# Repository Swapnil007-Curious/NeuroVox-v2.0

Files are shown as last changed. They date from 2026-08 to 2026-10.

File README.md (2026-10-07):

# NeuroVox v2.0

A forearm band that reads tiny muscle signals and turns them into spoken sentences. It's for people who can't talk anymore (ALS, stroke, vocal cord damage, some spinal injuries) but can still twitch a muscle in their forearm, which turns out to be most of them for a long time.

device-on-hand

**Hardware:** ₹10,000
**Software (companion website + AI voice):** ₹20,000 per year

For comparison, commercial AAC devices (eye trackers, switch boards, dedicated speech generators) go for roughly ₹85,000 to well over ₹12 lakh, and most of them need a clinician to set up. That gap is basically the whole reason this project exists.

---

## Why

Stephen Hawking ran his whole speech system off one cheek muscle. The idea here is the same, just moved to the forearm and built out of parts you can actually order from LCSC.

The part I cared about most is the output. A lot of cheap assistive projects stop at "the device can say yes or no." That's not much better than a call bell. NeuroVox only classifies four gestures on the board, but the companion website hands that label to an LLM along with the time of day, who the person is talking to, and what was just said, and gets back a real sentence. Same YES gesture can come out as "Yes, the pain's still there" or "Yes, let's go outside" depending on what was asked a second ago.

---

## How it works

1. **Electrodes.** Four standard 2" x 2" TENS pads stick on the skin. Two go over the flexor digitorum superficialis (inner forearm) and two over the extensor digitorum (outer forearm). Leads plug into the board through JST-SH connectors. The pads are NOT built into the enclosure, I tried that early on and it doesn't work because the two muscle groups are on opposite sides of the arm.
2. **Analog front end.** Four AD8232s amplify and filter the microvolt signals. An INA333 does extra differential conditioning on two channels.
3. **ADC.** An ADS1299 (24 bit, biosignal grade) samples all four channels over SPI. Way better resolution than the ESP32's own ADC.
4. **Classification on the board.** The ESP32-S3 smooths each channel into an envelope, compares it to a threshold that adapts to the person over time, and counts pulses. 1 pulse = YES, 2 = NO, 3 = HELP, 4 or more = WAIT. A BNO055 IMU throws out samples when the arm moves suddenly so a wave of the hand doesn't get read as a gesture.
5. **Bluetooth.** The gesture label plus a confidence score goes out over BLE (something like `CH1:YES:91%`).
6. **Sentence + voice.** The companion website receives it, gets a sentence from Claude, shows it on screen and speaks it out loud in the chosen language (English, Hindi, Marathi, Tamil, Bengali and a few others).

Muscle twitch to spoken sentence is meant to land in under two seconds, most of that is network time not the board.

---

## The board



2 layer FR4, **220mm x 50mm**, designed in KiCad 8. It's long and skinny on purpose so it runs along the forearm instead of across it.

The board is split into three zones along its length:

| Zone | Position | What's in it |
|---|---|---|
| Power | 0 to 60mm | MCP73831 Li-Po charger, TPS61023 boost (5V), AMS1117 3.3V regulator, USB-C input |
| Analog | 60 to 150mm | 4x AD8232, ADS1299, INA333, electrode connectors J3 to J6 |
| Digital | 150 to 220mm | ESP32-S3-WROOM-1-N8, BNO055 IMU, DRV2605L haptic driver, MAX98357A audio amp, RGB LEDs, buzzer, programming header J7 |

Analog and digital grounds are separate pours that only meet at one point, a ferrite bead right where the analog zone ends. The ESP32's antenna sits at the right edge with no copper under it.

**Why 220mm and not 200mm:** the first version was 200mm and the analog section was too packed. There was one ground connection near the instrumentation amp that just could not be routed, I checked it with an exhaustive pathfinding run, not just the autorouter giving up. Stretching the board 20mm and giving the analog zone 90mm instead of 65mm fixed it. If you fork this and want it smaller, expect that fight again.

### Pin map (real hardware)

| Function | GPIO |
|---|---|
| ADS1299 SPI CLK / MOSI / MISO / CS / DRDY | 10, 11, 12, 13, 14 |
| I2C SDA / SCL (BNO055, DRV2605L) | 21, 18 |
| Haptic enable | 8 |
| I2S to MAX98357A | 15, 16, 17 |
| Status LEDs | 2, 4, 47 |
| Buzzer | 48 |

### Fab notes

- You need **Standard PCBA** at JLCPCB, not Economic. The ESP32-S3 module, the MAX98357A (WLCSP) and the DRV2605L (DSBGA) aren't hand solderable at any sane yield.
- Standard PCBA adds temporary 5mm rails on the long edges for the pick and place machine. Ask for V-scores so they snap off and you get the real 220 x 50mm board back.
- The DRV2605L's center ball needs via-in-pad to escape. Mention it in the order notes.
- Gerbers and the full `.kicad_pcb` are in `/PCB`. I didn't make a separate schematic file for this revision.

---

## Firmware

FreeRTOS on the ESP32-S3, four tasks so the Bluetooth stack can't mess up sample timing:

| Task | Core | Priority | Job |
|---|---|---|---|
| ADC sampling | 0 | 5 | reads all 4 channels into a ring buffer |
| Gesture classifier | 1 | 3 | envelope, adaptive threshold, pulse counting, confidence |
| BLE dispatcher | 1 | 1 | sends gesture strings to the website |
| IMU monitor | 1 | 1 | flags motion over 1.5G so those samples get dropped |

A few details that matter for accuracy:

- Envelope is an exponential moving average (alpha 0.05).
- Contractions shorter than 30ms are ignored, they're almost always noise.
- A gesture only gets confirmed after 400ms of quiet, so a slow double pulse doesn't get read as two singles.
- The threshold for each channel updates off a rolling average of recent peaks, because signal strength changes person to person and also drifts for the same person as muscles get tired. A threshold set on day one is wrong by day thirty, especially with something progressive like ALS.
- All four channels are treated the same. An older board revision had a ground problem on two channels and the firmware briefly weighted them differently, that got removed once the redesign fixed the actual problem.

BLE service UUID: `180d1000-1234-1000-8000-00805f9b34fb`
Characteristic: `2a371000-1234-1000-8000-00805f9b34fb`
Device name: `NeuroVox-v2`

**Current state, honestly:** the firmware in `/FIRMWARE` is a validation build. It runs the full classification pipeline against potentiometers standing in for the EMG front end and an MPU6050 standing in for the BNO055, which let me test the logic without waiting on boards. Flip `SIM_BUILD` to false for hardware. The piece still left is swapping the analog reads for a proper SPI driver talking to the ADS1299 and moving I2C to GPIO21/18. That happens when the assembled boards are back.

**On accuracy:** my target is around 88 to 90% gesture accuracy after a short per person calibration (about 10 contractions per gesture), tested seated with the arm resting. I haven't measured that on real muscle yet because the boards aren't made yet, so please don't quote it as a result. When I test I'll report each channel separately and then combined.

---

## Enclosure

ezgif-frame-200

Two part snap fit, no screws holding the halves together (four M2 screws just hold the PCB to standoffs inside the top shell).

| File | Size | Notes |
|---|---|---|
| `TOP.stl` | 224 x 54 x 10mm | rigid shell, cutouts for USB-C, programming header, speaker grille, LED window, buzzer, vent slots, antenna window thinned to 1mm |
| `BOTTOM.stl` | 224 x 94.4 x 9.8mm | the skin side, strap wings stick out 20mm each side, cable clips for the electrode leads, battery bay |
| `FULL.stl` | 224 x 94.4 x 16mm | both halves together, for viewing. It isn't watertight because two meshes are combined, that's expected |

0.3mm interference lip, four alignment pegs. So the full width with strap wings is about 94mm, not 54mm, keep that in mind.

**Print it in:** PETG for the top (ABS warps badly at 224mm long on an open printer), TPU 95A for the bottom since it sits on skin for hours and the strap wings need to flex. Don't use PLA, it gets soft around 60C and tacky against skin.

---

## Bill of materials

Main parts:

| Part | LCSC |
|---|---|
| ESP32-S3-WROOM-1-N8 | C2913198 |
| ADS1299IPAGR | C476817 |
| AD8232ACPZ-R7 (x4) | C43216 |
| INA333AIDGKR | C19450 |
| BNO055BST | C93216 |
| DRV2605LYZFR | C2869341 |
| MAX98357AEWL+T | C2682619 |
| MCP73831T-2ACI/OT | C424093 |
| TPS61023DRLR | C919459 |
| AMS1117-3.3 | C6186 |
| USB-C TYPE-C-31-M-12 | C165948 |
| JST-SH 3 pin (x4, electrodes) | C160403 |
| JST-PH 2 pin (battery) | C265016 |

Bought separately: 5000mAh 3.7V Li-Po with a JST-PH lead, a pack of 2" x 2" TENS pads (you need 8 per session), TENS snap leads, a 25mm strap with velcro or a buckle, and the printed shells.

Two things to watch before ordering:
- **FB1 ferrite bead:** the exact BLM18PG601SN1D wasn't confirmed on LCSC. BLM18AG601SN1D (C19330) is the same value and package but a different current series, check the datasheet first.
- **BZ1 buzzer:** the PUI SMT-0825-S-4-R isn't on LCSC at all. Get it from DigiKey or Mouser and solder it after, it's just two pads.
- Also the ADS1299 is the expensive one and the BNO055 has a history of going out of stock. Check live stock right before you order.

---

## Software side

There's no separate phone app. Everything runs inside the NeuroVox website.

- The public site explains the device. The actual companion app is behind an activation code that comes in the box, so only owners can get in.
- Bluetooth runs through the Web Bluetooth API. Works in Chrome on Android and desktop. Doesn't work on iPhone Safari, that's an Apple limitation, there's a demo mode for that case.
- Speech uses the browser's built in text to speech, so no extra voice API is needed.
- The Claude API call goes through a server side function so the API key never sits in the browser.
- Inside the app: live gesture and sentence display, conversation history with translation, charts (hourly activity, weekly trend, gesture mix, live signal trace), device status and a signal test.

The software subscription (₹20,000 a year) covers the AI sentence generation, which is a real running cost per message, plus updates.

---

## What's done and what isn't

Done:
- PCB layout, fab ready
- Enclosure, both halves, printable
- Firmware classification pipeline, tested in simulation
- BOM with verified part numbers
- Companion website with the gated app

Not done yet:
- Boards aren't fabricated, waiting on funding
- ADS1299 SPI driver for the real board
- Real accuracy numbers on actual people
- Voice cloning (record someone's voice before they lose it, then speak in it later). The hook is in the code but nothing's connected
- A two step gesture menu (pick a category like body, food, comfort, emergency, then pick inside it) so people can say more specific things

---

## Not a medical device

NeuroVox is a student research project. It isn't certified or clinically validated, and it shouldn't replace an AAC device a clinician has prescribed or be the only way someone calls for help in an emergency. If you're a caregiver please stay involved and don't rely only on what the band says.

---

## Links

- Main repo: https://github.com/Swapnil007-Curious/NeuroVox-v2.0
- CAD: https://github.com/Swapnil007-Curious/NeuroVox-v2.0/tree/main/CAD
- PCB: https://github.com/Swapnil007-Curious/NeuroVox-v2.0/tree/main/PCB
- Firmware: https://github.com/Swapnil007-Curious/NeuroVox-v2.0/tree/main/FIRMWARE

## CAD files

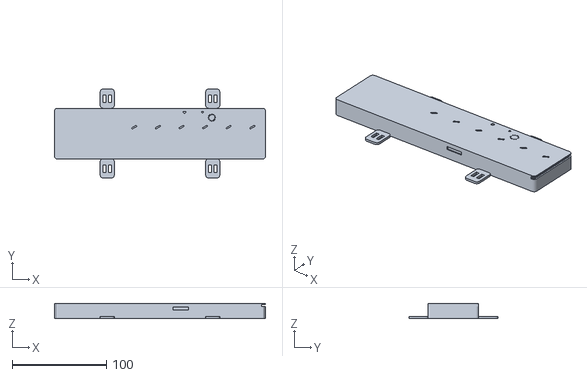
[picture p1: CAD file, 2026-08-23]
CAD/FULL.stl
224.0 x 94.4 x 16.0

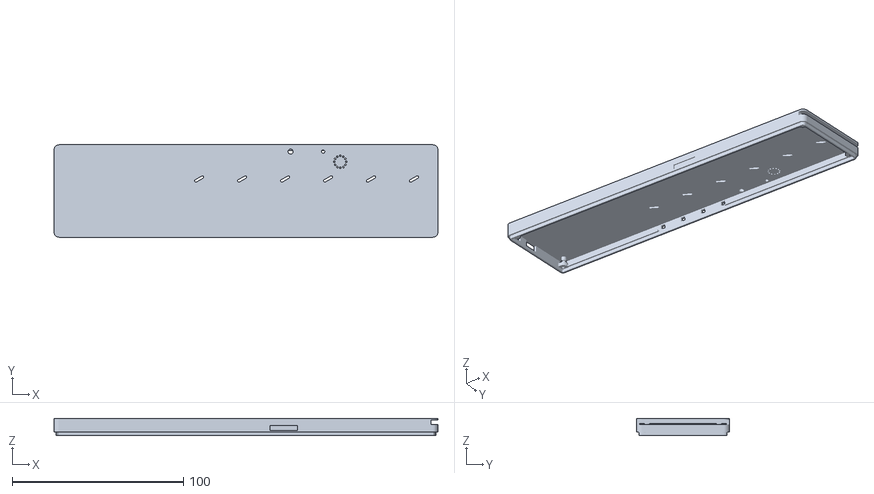
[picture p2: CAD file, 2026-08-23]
CAD/TOP.stl
224.0 x 54.0 x 10.0

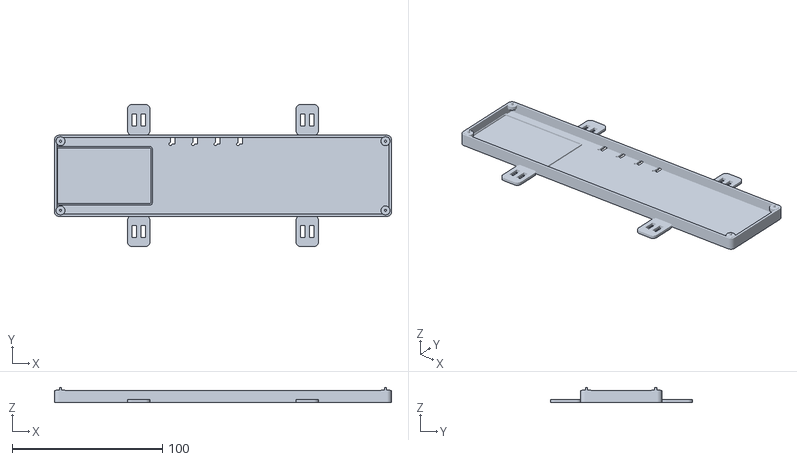
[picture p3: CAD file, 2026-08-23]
CAD/BOTTOM.stl
224.0 x 94.4 x 9.80

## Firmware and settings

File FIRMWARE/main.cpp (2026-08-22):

// NeuroVox v2.0 - EMG gesture communication device
// Target board: 220mm x 50mm 2-layer PCB, ESP32-S3
// Development/validation build (potentiometer + MPU6050 stand-ins for
// the analog front end and IMU while the assembled board is in transit)

#include <Arduino.h>
#include <BLE2902.h>
#include <BLEDevice.h>
#include <BLEServer.h>
#include <BLEUtils.h>
#include <Wire.h>
#include <math.h>

#define SIM_BUILD true // set false once flashing the assembled board

// Pin map (validation build)
#define EMG_CH1 1
#define EMG_CH2 2
#define EMG_CH3 3
#define EMG_CH4 4
#define LED_PIN 15
#define I2C_SDA 8
#define I2C_SCL 9
#define MPU_ADDR 0x68

// Detection parameters
#define ALPHA 0.05f
#define SILENCE_MS 400
#define MIN_PULSE_MS 30 // rejects sub-30ms noise spikes
#define BASE_THRESHOLD 1800
#define LOW_CONF_CUTOFF 70
#define ACCEL_LIMIT_G 1.5f
#define ROLLING_WINDOW_DAYS 7
#define BUFFER_SIZE 128

struct EMGSample {
  uint16_t ch[4];
  uint32_t time_ms;
  bool motionFlag;
};

struct GestureMessage {
  char text[64];
};

EMGSample ringBuffer[BUFFER_SIZE];
volatile uint8_t bufHead = 0;
volatile uint8_t bufTail = 0;

float dailyPeak[4] = {0, 0, 0, 0};
float rollingAvg[4] = {2000, 2000, 2000, 2000};
float adaptiveThreshold[4] = {BASE_THRESHOLD, BASE_THRESHOLD, BASE_THRESHOLD,
                              BASE_THRESHOLD};

volatile bool motionDetected = false;

#define SERVICE_UUID "180d1000-1234-1000-8000-00805f9b34fb"
#define CHAR_UUID "2a371000-1234-1000-8000-00805f9b34fb"

BLEServer *pServer = nullptr;
BLECharacteristic *pCharacteristic = nullptr;
bool deviceConnected = false;

QueueHandle_t gestureQueue;

TaskHandle_t samplingTaskHandle = nullptr;
TaskHandle_t classifierTaskHandle = nullptr;
TaskHandle_t bleTaskHandle = nullptr;
TaskHandle_t imuTaskHandle = nullptr;

class ServerCallbacks : public BLEServerCallbacks {
  void onConnect(BLEServer *s) override {
    deviceConnected = true;
    Serial.println("phone connected");
  }
  void onDisconnect(BLEServer *s) override {
    deviceConnected = false;
    Serial.println("phone disconnected, restarting advertising");
    BLEDevice::startAdvertising();
  }
};

float readAccelMagnitude() {
  Wire.beginTransmission(MPU_ADDR);
  Wire.write(0x3B);
  if (Wire.endTransmission(false) != 0) {
    return 1.0f;
  }
  Wire.requestFrom(MPU_ADDR, 6, true);

  if (Wire.available() >= 6) {
    int16_t ax = (Wire.read() << 8) | Wire.read();
    int16_t ay = (Wire.read() << 8) | Wire.read();
    int16_t az = (Wire.read() << 8) | Wire.read();

    float axg = ax / 16384.0f;
    float ayg = ay / 16384.0f;
    float azg = az / 16384.0f;

    return sqrtf(axg * axg + ayg * ayg + azg * azg);
  }
  return 1.0f;
}

void imuTask(void *param) {
  while (true) {
    float magnitude = readAccelMagnitude();
    motionDetected = (magnitude > ACCEL_LIMIT_G);
    vTaskDelay(pdMS_TO_TICKS(10));
  }
}

void samplingTask(void *param) {
  const TickType_t period = SIM_BUILD ? pdMS_TO_TICKS(20) : pdMS_TO_TICKS(1);
  TickType_t start = xTaskGetTickCount();

  while (true) {
    EMGSample s;
    s.ch[0] = analogRead(EMG_CH1);
    s.ch[1] = analogRead(EMG_CH2);
    s.ch[2] = analogRead(EMG_CH3);
    s.ch[3] = analogRead(EMG_CH4);
    s.time_ms = millis();
    s.motionFlag = motionDetected;

    uint8_t nextHead = (bufHead + 1) % BUFFER_SIZE;
    if (nextHead != bufTail) {
      ringBuffer[bufHead] = s;
      bufHead = nextHead;
    }

    vTaskDelayUntil(&start, period);
  }
}

void classifierTask(void *param) {
  float envelope[4] = {0, 0, 0, 0};
  float peakThisGesture[4] = {0, 0, 0, 0};
  bool inGesture[4] = {false, false, false, false};
  uint32_t gestureStart[4] = {0, 0, 0, 0};
  int pulseCount[4] = {0, 0, 0, 0};
  uint32_t lastPulse[4] = {0, 0, 0, 0};
  uint32_t lastDailyUpdate = millis();

  while (true) {
    if (bufTail == bufHead) {
      vTaskDelay(pdMS_TO_TICKS(10));
      continue;
    }

    EMGSample s = ringBuffer[bufTail];
    bufTail = (bufTail + 1) % BUFFER_SIZE;

    if (s.motionFlag) {
      continue;
    }

    uint32_t now = s.time_ms;

    for (int ch = 0; ch < 4; ch++) {
      float rectified = fabsf((float)s.ch[ch] - 2048.0f);
      envelope[ch] = ALPHA * rectified + (1.0f - ALPHA) * envelope[ch];

      if (envelope[ch] > peakThisGesture[ch]) {
        peakThisGesture[ch] = envelope[ch];
      }

      if (!inGesture[ch] && envelope[ch] > adaptiveThreshold[ch]) {
        inGesture[ch] = true;
        gestureStart[ch] = now;
        peakThisGesture[ch] = envelope[ch];
      }

      if (inGesture[ch] && envelope[ch] < (adaptiveThreshold[ch] * 0.6f)) {
        inGesture[ch] = false;

        // ignore contractions shorter than MIN_PULSE_MS, treat as noise
        if (now - gestureStart[ch] >= MIN_PULSE_MS) {
          pulseCount[ch]++;
          lastPulse[ch] = now;

          if (peakThisGesture[ch] > dailyPeak[ch]) {
            dailyPeak[ch] = peakThisGesture[ch];
          }
        }
      }

      if (!inGesture[ch] && pulseCount[ch] > 0 &&
          (millis() - lastPulse[ch]) > SILENCE_MS) {

        float margin = (peakThisGesture[ch] - adaptiveThreshold[ch]) /
                       adaptiveThreshold[ch] * 100.0f;
        float confidence = constrain(60.0f + margin, 0.0f, 100.0f);
        bool lowConf = confidence < LOW_CONF_CUTOFF;

        GestureMessage msg;
        const char *gestureName;
        switch (pulseCount[ch]) {
        case 1:
          gestureName = "YES";
          break;
        case 2:
          gestureName = "NO";
          break;
        case 3:
          gestureName = "HELP";
          break;
        default:
          gestureName = "WAIT";
          break;
        }

        snprintf(msg.text, sizeof(msg.text), "CH%d:%s:%.0f%%%s", ch + 1,
                 gestureName, confidence, lowConf ? ":LOWCONF" : "");

        pulseCount[ch] = 0;
        xQueueSend(gestureQueue, &msg, 0);
      }
    }

    if (millis() - lastDailyUpdate > 60000) {
      lastDailyUpdate = millis();
      for (int ch = 0; ch < 4; ch++) {
        rollingAvg[ch] =
            (rollingAvg[ch] * (ROLLING_WINDOW_DAYS - 1) + dailyPeak[ch]) /
            ROLLING_WINDOW_DAYS;

        if (dailyPeak[ch] > rollingAvg[ch] * 0.8f) {
          adaptiveThreshold[ch] = rollingAvg[ch] * 0.9f;
        }
        dailyPeak[ch] = 0;
      }
    }
  }
}

void bleBroadcastTask(void *param) {
  GestureMessage incomingMsg;
  while (true) {
    if (xQueueReceive(gestureQueue, &incomingMsg, portMAX_DELAY) == pdTRUE) {
      Serial.print("gesture: ");
      Serial.println(incomingMsg.text);

      if (!SIM_BUILD && deviceConnected && pCharacteristic != nullptr) {
        pCharacteristic->setValue((uint8_t *)incomingMsg.text,
                                  strlen(incomingMsg.text));
        pCharacteristic->notify();
      }

      digitalWrite(LED_PIN, HIGH);
      vTaskDelay(pdMS_TO_TICKS(100));
      digitalWrite(LED_PIN, LOW);
    }
  }
}

void setup() {
  Serial.begin(115200);
  delay(1000);
  Serial.println("NeuroVox v2.0 booting");

  pinMode(LED_PIN, OUTPUT);
  digitalWrite(LED_PIN, LOW);

  analogReadResolution(12);
  analogSetAttenuation(ADC_11db);

  Wire.begin(I2C_SDA, I2C_SCL);

  gestureQueue = xQueueCreate(10, sizeof(GestureMessage));
  if (gestureQueue == nullptr) {
    Serial.println("queue creation failed");
    while (true) {
      delay(1000);
    }
  }

  if (!SIM_BUILD) {
    BLEDevice::init("NeuroVox-v2");
    pServer = BLEDevice::createServer();
    pServer->setCallbacks(new ServerCallbacks());

    BLEService *pService = pServer->createService(SERVICE_UUID);
    pCharacteristic = pService->createCharacteristic(
        CHAR_UUID, BLECharacteristic::PROPERTY_NOTIFY);
    pCharacteristic->addDescriptor(new BLE2902());
    pService->start();

    BLEAdvertising *pAdvertising = BLEDevice::getAdvertising();
    pAdvertising->addServiceUUID(SERVICE_UUID);
    pAdvertising->setScanResponse(true);
    BLEDevice::startAdvertising();
    Serial.println("BLE radio started");
  } else {
    Serial.println("BLE bypassed for this build");
  }

  xTaskCreatePinnedToCore(samplingTask, "ADC_Sample", 3072, nullptr, 5,
                          &samplingTaskHandle, 0);
  xTaskCreatePinnedToCore(classifierTask, "Classifier", 4096, nullptr, 3,
                          &classifierTaskHandle, 1);
  xTaskCreatePinnedToCore(bleBroadcastTask, "BLE_Tx", 4096, nullptr, 1,
                          &bleTaskHandle, 1);
  xTaskCreatePinnedToCore(imuTask, "IMU_Monitor", 2048, nullptr, 1,
                          &imuTaskHandle, 1);

  Serial.println("all tasks running");
}

void loop() { vTaskDelay(portMAX_DELAY); }

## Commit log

2026-06-16 COMPUTER-AIDED DESIGN OF THIS PROJECT .
    THIS IS THE CAD OF THIS PROJECT . THIS MODEL INCLUDES A SPACE FOR THE PCB , BATTERY AND ELECTRODE CONNECTIONS .
    [FULL PART.step]
2026-07-10 Bill Of Materials
    [BOM.csv]
2026-07-10 BOM for PCB Assembly
    [PCB BOM.xlsx]
2026-08-21 NeuroVox v2.0 PCB File
2026-08-22 PCB Files
2026-08-23 CAD Files
    [BOTTOM.stl, FULL.stl, TOP.stl]
2026-08-23 BOM AND CPL Files
    [NeuroVox v2.0 BOM.csv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]
2026-08-23 BOM File
    [NeuroVox v2.0 BOM.csv]
2026-08-23 PCB File
    [NeuroVox v2.0.kicad_pcb]
2026-08-23 PCB Gerbers ZIP
